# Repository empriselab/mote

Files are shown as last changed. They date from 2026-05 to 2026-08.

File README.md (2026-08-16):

# Mote





The low cost, high reliability mobile robot for hands-on robotics education.

[](mote/mote-book/src/assets/glam.webp)

## Motivation

Robotics is more fun with real hardware.

["Low cost"](https://www.robotshop.com/products/clearpath-robotics-turtlebot-4-mobile-robot) robots are prohibitively expensive for aspiring engineers.
We believe robotics should be affordable, enjoyable, and obtainable. So we made Mote.

## History

Mote is the spiritual successor of [the Little Red Rover project](https://github.com/little-red-rover).

For the past two years, Little Red Rover has been used to teach the Foundations of Robotics course at Cornell University.
Mote is the product of the many lessons learned during that effort.

## Contributing

Want to patch a bug, add a feature, or otherwise improve Mote?
Checkout [the contribution guide](https://empriselab.github.io/mote/advanced/contributing/contributing.html).

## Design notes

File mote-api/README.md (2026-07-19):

# mote-api

sans-io message and wire-protocol definitions for the Mote firmware <--> host driver link. 
`no_std` + `alloc`.

## Usage

```rust
use mote_api::{HostLink, MoteLink};
use mote_api::messages::host_to_mote;

let mut host_side = MoteLink::new();
let mut mote_side = HostLink::new();

host_side.send(host_to_mote::Message::Ping).unwrap();
while let Some(packet) = host_side.poll_transmit() {
    mote_side.handle_receive(&packet);
}
assert_eq!(mote_side.poll_receive().unwrap(), Some(host_to_mote::Message::Ping));
```

See [docs.rs/mote-api](https://docs.rs/mote-api) for the full API.

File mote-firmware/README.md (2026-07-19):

# mote-firmware

Embassy firmware for the RP2534 that runs mote.

## Build and Deploy

Requirements:
* [cargo](https://rustup.rs) (rust package manager)
* [go-task](https://taskfile.dev/installation/) (task runner)
* [probe-rs](https://probe.rs/docs/getting-started/installation/) (flasher / debugger)

From this folder, run

```
task deploy
```

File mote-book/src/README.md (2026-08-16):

<pre style="text-align: center">
         ┓            ┏         
░░░░░▒▒▒▓┃ ┳┳┓┏┓┏┳┓┏┓ ┃▓▒▒▒░░░░░
░░░░░▒▒▒▓┃ ┃┃┃┃┃ ┃ ┣  ┃▓▒▒▒░░░░░
░░░░░▒▒▒▓┃ ┛ ┗┗┛ ┻ ┗┛ ┃▓▒▒▒░░░░░
         ┛            ┗         
</pre>

<p style="text-align: center"> The low-cost, high-reliablity mobile robot for hands-on robotics education. </p>

<br>
<br>

<div class="image-split">
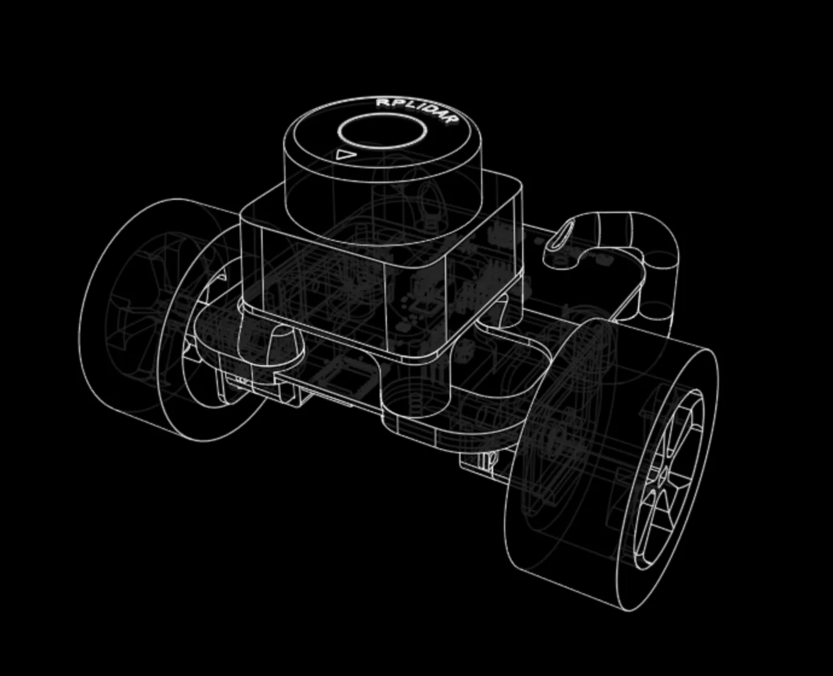
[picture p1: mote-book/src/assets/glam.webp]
    
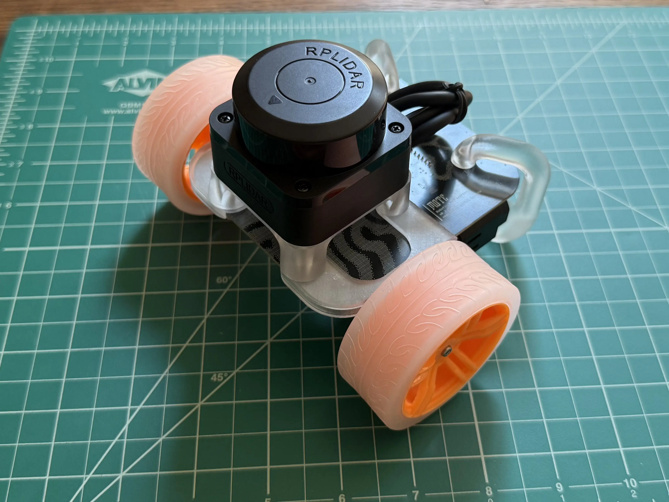
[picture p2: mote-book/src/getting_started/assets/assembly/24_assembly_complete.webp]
    
</div>

<div class="desktop-only">
    <iframe src="https://app.rerun.io/version/0.34.1/index.html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" width="100%" style="aspect-ratio: 1.5;"></iframe>
</div>

## Highlights

* LiDAR, IMU, and wheel position data streamed over WiFi
* Polished SDKs for ROS, ROS2, Python and Rust
* Wide cross-platform support
* Open source firmware, software, and hardware
* Only $100

## Getting Started

[Assemble your kit](./getting_started/kit-assembly.md) if you already have the parts, or checkout the [hardware sourcing guide](./hardware-sourcing/acquire.md) if you're starting from scratch.

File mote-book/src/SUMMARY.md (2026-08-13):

# Summary

[Home](README.md)

# Getting Started

- [Kit Assembly](./getting_started/kit-assembly.md)
- [Updating Firmware](./getting_started/updating.md)
- [Configuration](./getting_started/configuration.md)
- [Hello World](./getting_started/hello-world.md)

# Guides

- [Python]()
    - [Visualization]()
    - [Teleop]()

- [Rust]()
    - [Visualization]()
    - [Teleop]()

- [ROS Noetic (EOL)]()
    - [Visualization]()
    - [Teleop]()
    - [Navigation]()

- [ROS2]()
    - [Visualization]()
    - [Teleop]()
    - [Nav2]()

# Troubleshooting

- [Common Issues](./troubleshooting/common_issues.md)
- [Status LEDs](./troubleshooting/status_leds.md)

# Hardware Sourcing

- [Get Your Mote](./hardware-sourcing/acquire.md)
- [Bill of Materials]()
- [Ordering Circuit Boards]()
- [3D Printed Parts]()

# Advanced

- [Contributing](./advanced/contributing/contributing.md)
    - [Development Environment](./advanced/contributing/dev_env.md)
    - [Building, Testing, Running, and Releasing](./advanced/contributing/build_test_deploy.md)
    - [Hardware](./advanced/contributing/hardware.md)

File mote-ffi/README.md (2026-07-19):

# mote-ffi

FFI glue exposing [mote-api](../mote-api)'s message protocol to Python, WASM, and C++.

## Python: `mote_link`

The Python package. See [`mote_link/README.md`](mote_link/README.md) for
installation and usage.

```bash
task dev-setup   # builds the extension and regenerates types
task test        # cargo test + wasm-pack test + pytest
```

## C++

```bash
task build-cxx
```

Builds a static library (`target/release/libmote_ffi.a`) and cxx-generated headers
(`include/mote-ffi/src/mote_cxx.rs.h`, `include/rust/cxx.h`). `#include "mote-ffi/src/mote_cxx.rs.h"`
to get the `mote::MoteLink` class, `mote::SendResult`/`mote::ReceiveResult`, and
`mote::MoteLinkErrorCode`. #

# WASM / TypeScript

```bash
task build-wasm
```

Builds a `wasm-pack` package (`target/pkg-node`) exposing a `Link` class. See
`mote-configuration`'s `src/lib/link.ts` for an example consumer.

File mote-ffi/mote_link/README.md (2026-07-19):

# mote_link

Python client for talking to [Mote](https://empriselab.github.io/mote/) robots over the network.

`mote_link` handles discovery (via mDNS), connection, and message serialization / deserialization.

## Installation

```bash
pip install mote_link
```

Add the `demo` extra (`pip install mote_link[demo]`) to also install `rerun-sdk` and
`pyglet`, needed only by the bundled `rerun-demo` example.

## Example

```python
import asyncio

from mote_link import MoteClient, SetDriveBaseVelocity, DriveBaseState

async def main():
    async with MoteClient() as mote:
        # Opens an interactive prompt if the robot's IP or UID isn't known.
        await mote.connect()

        # Drive both wheels forward.
        await mote.send(SetDriveBaseVelocity(left_velocity_rad_per_s=1.0, right_velocity_rad_per_s=1.0))

        # Read messages from the robot.
        message = await mote.recv()
        if isinstance(message, DriveBaseState):
            print(f"left: {message.left}, right: {message.right}")

asyncio.run(main())
```

## Documentation

See the [Mote documentation](https://empriselab.github.io/mote/) for hardware setup, configuration,
and the full API reference.

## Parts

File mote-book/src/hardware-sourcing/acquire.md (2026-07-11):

# Get Your Mote

Mote uses a custom circuit board that must be manufactured and assembled at a factory.
While PCBA has become remarkably affordable in recent years, setup fees make the cost per unit high for small scale runs (1 - 10 units).

If you would like to order a small number of robots, please take a look on [the issue tracker](https://github.com/empriselab/mote/issues) and see if a group buy is being coordinated.
If you don't see a group buy posted, reach out to [a member of the Mote team](mailto:mmc323@cornell.edu) and we can help you start one.

If you would like to build many Motes you can start your own manufacturing run. Check out [Ordering Circuit Boards](./circuit-boards.md) for a step by step guide on the process.
It's much easier than it sounds.

All other (non-3D printed) parts are commercially available through standard channels. See the [Bill of Materials page](./bom.md) for details.

The rest of the robot is 3D printed. The [3D Printed Parts page](./printed.md) provides guidance for producing these parts.

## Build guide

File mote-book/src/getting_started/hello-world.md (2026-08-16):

# Hello World

In this example we'll use the mote-link Python library to control Mote and visualize telemetry data.

<div class="desktop-only">
    <iframe src="https://app.rerun.io/version/0.34.1/index.html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" width="100%" style="aspect-ratio: 1.5;"></iframe>

*Example data - Mote driving around my apartment*
</div>

<!-- <iframe src="https://app.rerun.io/version/0.34.1/index.html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" width="100%" style="aspect-ratio: 1.5;"></iframe> -->

## Setup

This example uses [uv](https://docs.astral.sh/uv/) to run a Python program. Install uv using the instructions in the [uv docs](https://docs.astral.sh/uv/getting-started/installation/).

Attach the battery to your Mote. Place your Mote on the ground with enough space for it to move around.

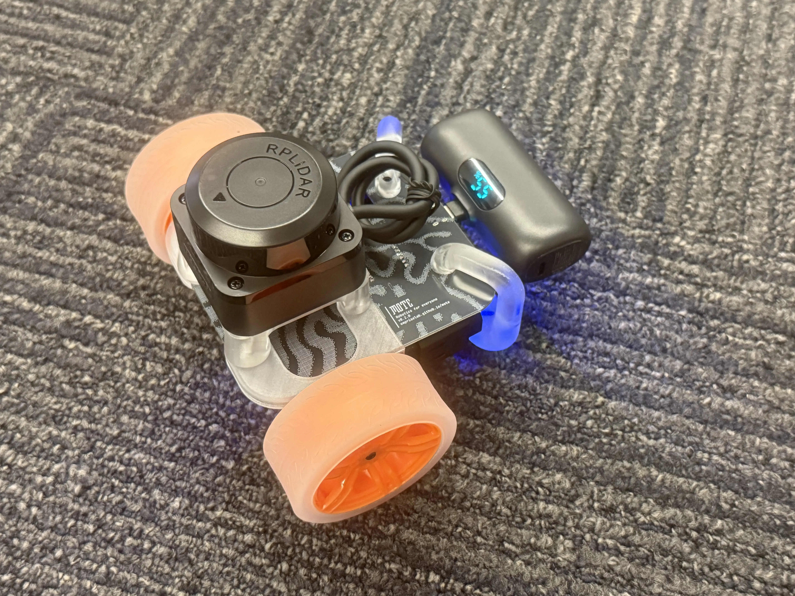
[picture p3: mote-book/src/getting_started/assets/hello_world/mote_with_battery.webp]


## Running the mote-link Demo

In the terminal of your choice, run the demo.

```bash
uvx --from 'mote-link[demo]' rerun-demo
```

Follow the instructions in your terminal to select and connect to your Mote. 

Once connected, your browser will open to a dashboard showing realtime LiDAR, wheel encoder, accelerometer, and gyroscope data.

Use the arrow keys to drive Mote around.

> [!TIP]
> If you know your robot's [name](./configuration.html#give-your-mote-a-name) or [ip address](./configuration.html#give-your-mote-a-name), you can skip waiting for autodiscovery by passing it in as an argument:
>
> `uvx --from 'mote-link[demo]' rerun-demo --ip 192.168.XX.XX` or 
> 
> `uvx --from 'mote-link[demo]' rerun-demo --name my-awesome-name`

## Next Steps

* [Python guide]() - learn how to write your own Python scripts for interfacing with Mote.
* [The Rust guide]() - like the Python guide, but using Rust 🦀.
* [The ROS 2 guide]() - learn how to use Mote with the Robot Operating System.

## Troubleshooting

### "Could not find Motes using autodiscovery"

Your network has mDNS disabled. This is common practice for public and corporate networks.
You can connect directly to your Mote via it's IP.

1. Connect the robot to your computer using a USB-C cable

2. Open [the Mote configuration page](../configuration).

3. Note the IP provided under "Identification".

4. Pass the IP into the demo command

```bash
uvx --from 'mote-link[demo]' rerun-demo --ip <IP from the configuration page>
```

Be aware that Mote's IP may change between sessions. If that happens, check the [configuration page](../configuration) for the new IP.

### My Mote drives backwards

[Check your motor cable connections](./kit-assembly.html#cables). Are the left and right motor connections swapped?

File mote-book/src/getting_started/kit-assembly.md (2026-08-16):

# Kit Assembly

In this tutorial you will assemble your Mote. It should take around 15 minutes.

## Gather Parts

First, check that you have the required parts.
Missing something? Check out [the sourcing guide](../hardware-sourcing/acquire.md).

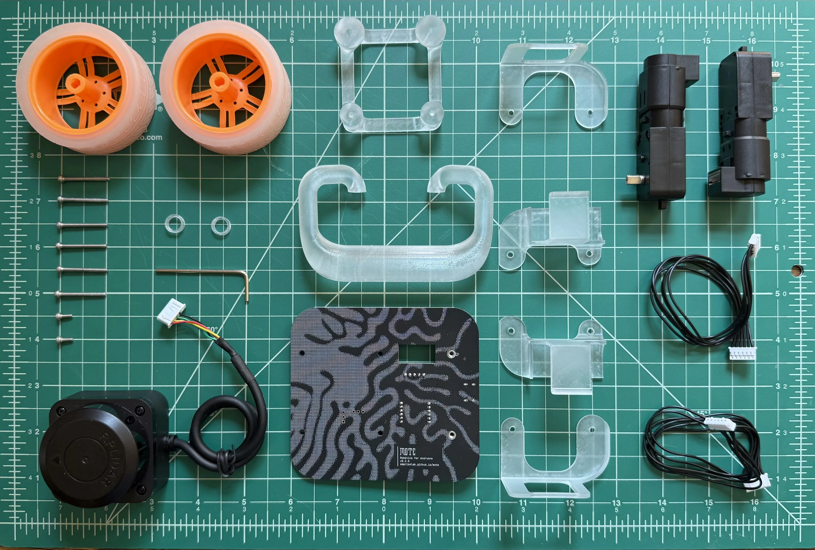
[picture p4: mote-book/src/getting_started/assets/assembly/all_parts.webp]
Required parts


| Item | Quantity | Picture | 
|---|---|---|
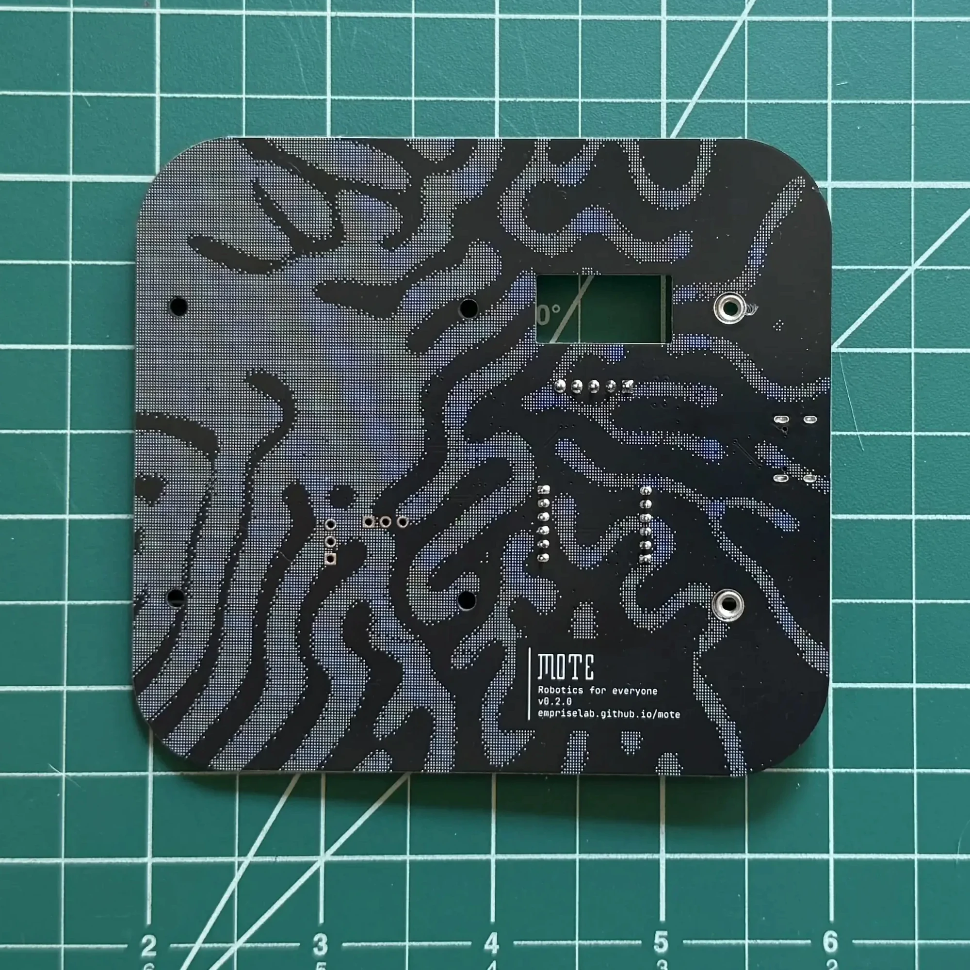
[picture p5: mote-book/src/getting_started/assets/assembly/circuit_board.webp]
| Circuit Board | 1 |  |
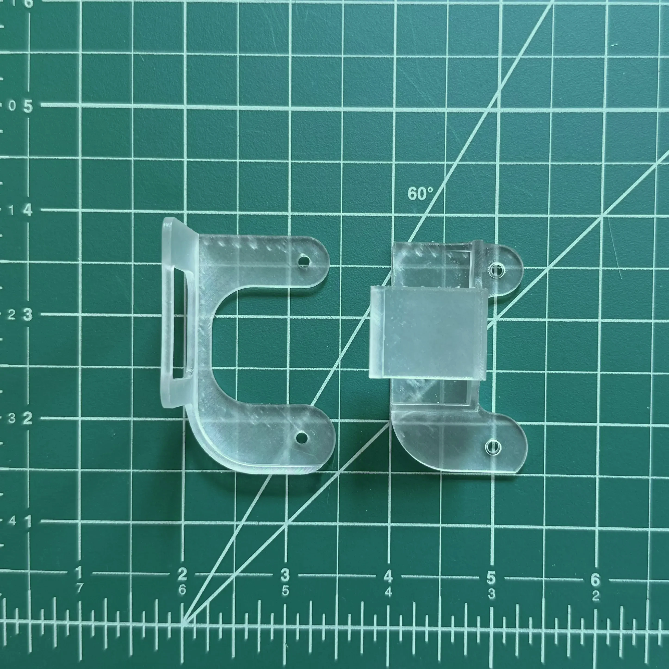
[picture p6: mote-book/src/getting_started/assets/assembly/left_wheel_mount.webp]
| Left Motor Mount | 1 |  |
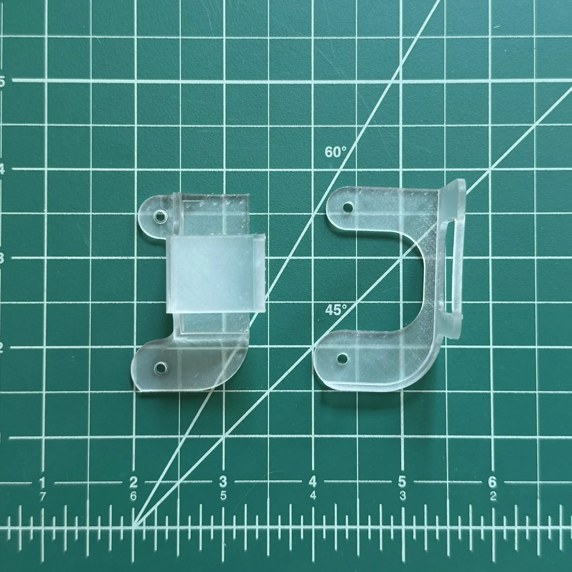
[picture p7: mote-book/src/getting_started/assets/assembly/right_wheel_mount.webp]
| Right Motor Mount | 1 |  |
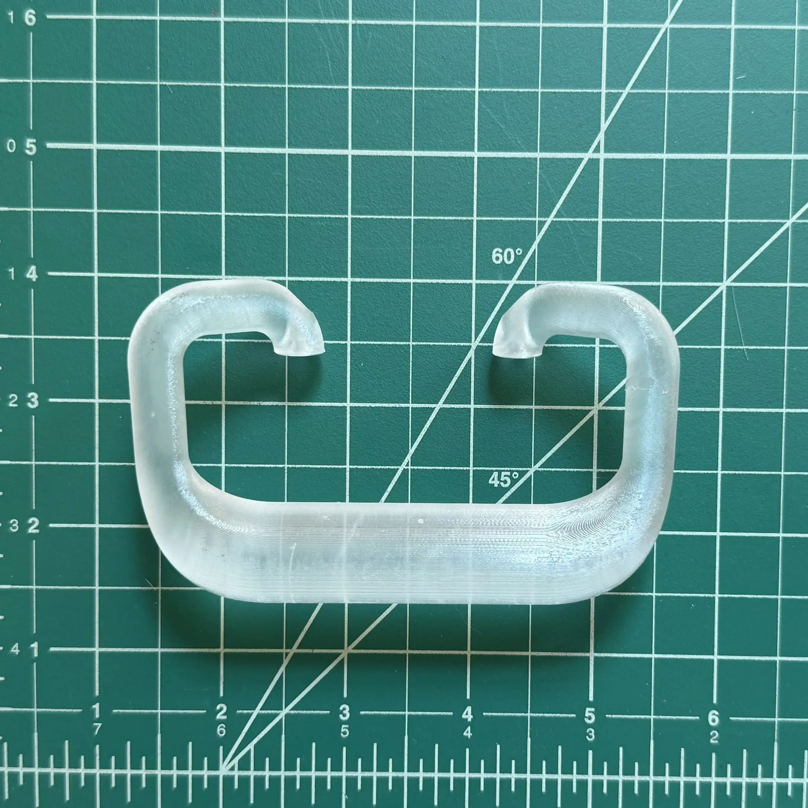
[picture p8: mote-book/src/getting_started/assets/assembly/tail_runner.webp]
| Tail Runner | 1 |  |
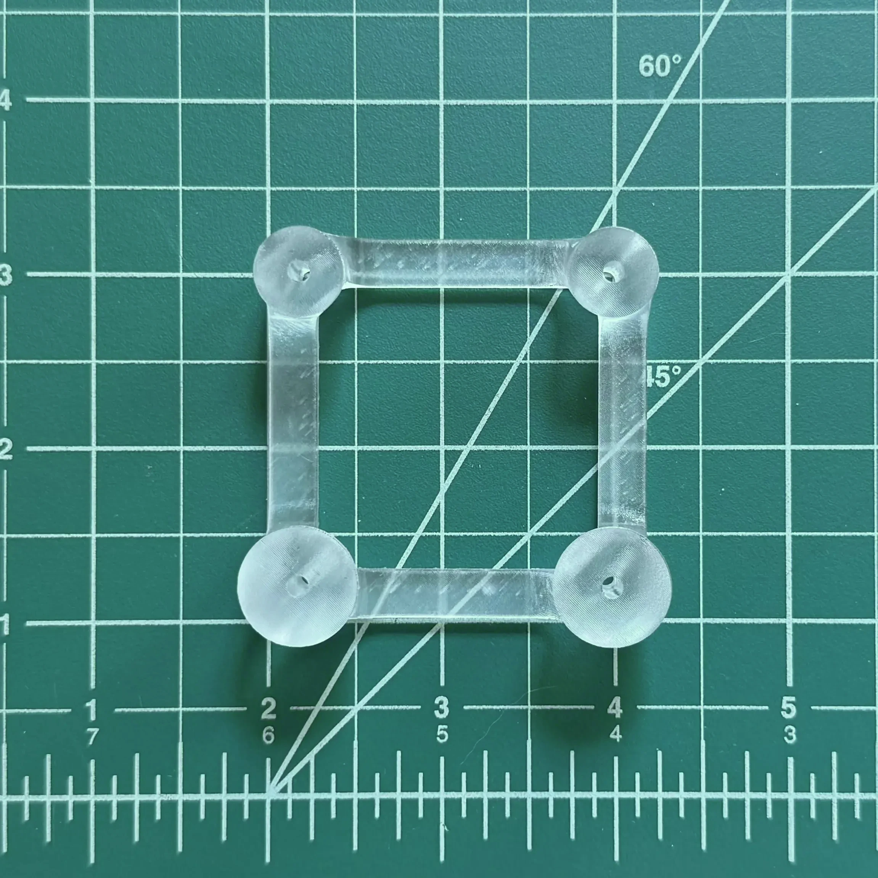
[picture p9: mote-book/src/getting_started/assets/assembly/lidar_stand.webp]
| LiDAR Mount | 1 |  |
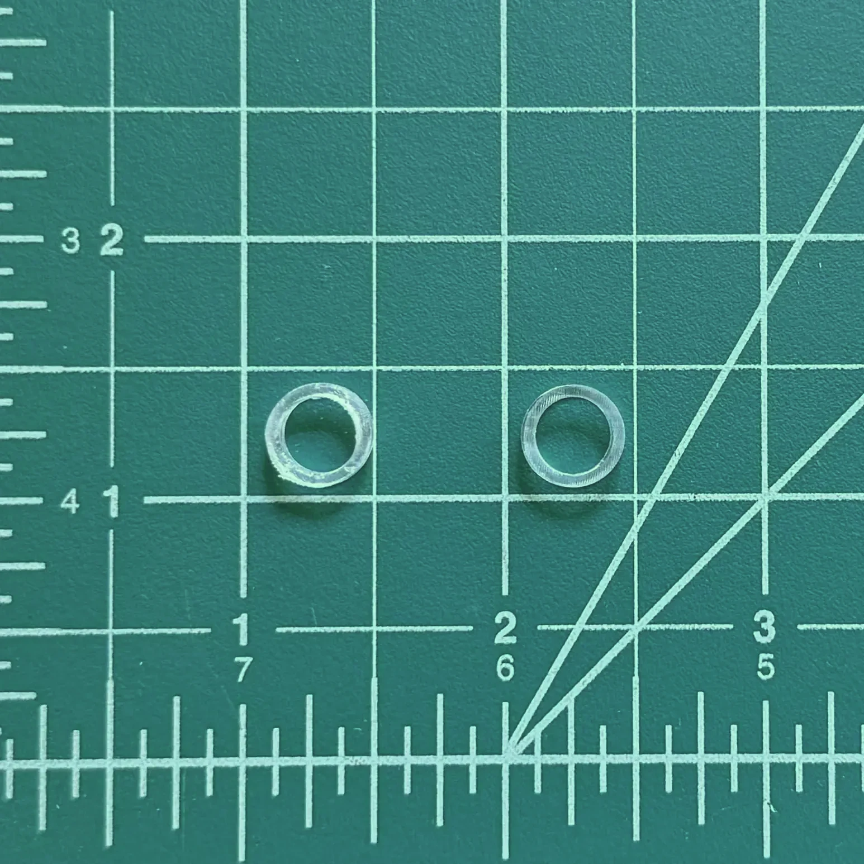
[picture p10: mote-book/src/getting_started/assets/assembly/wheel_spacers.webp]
| Wheel Spacers | 2 |  |
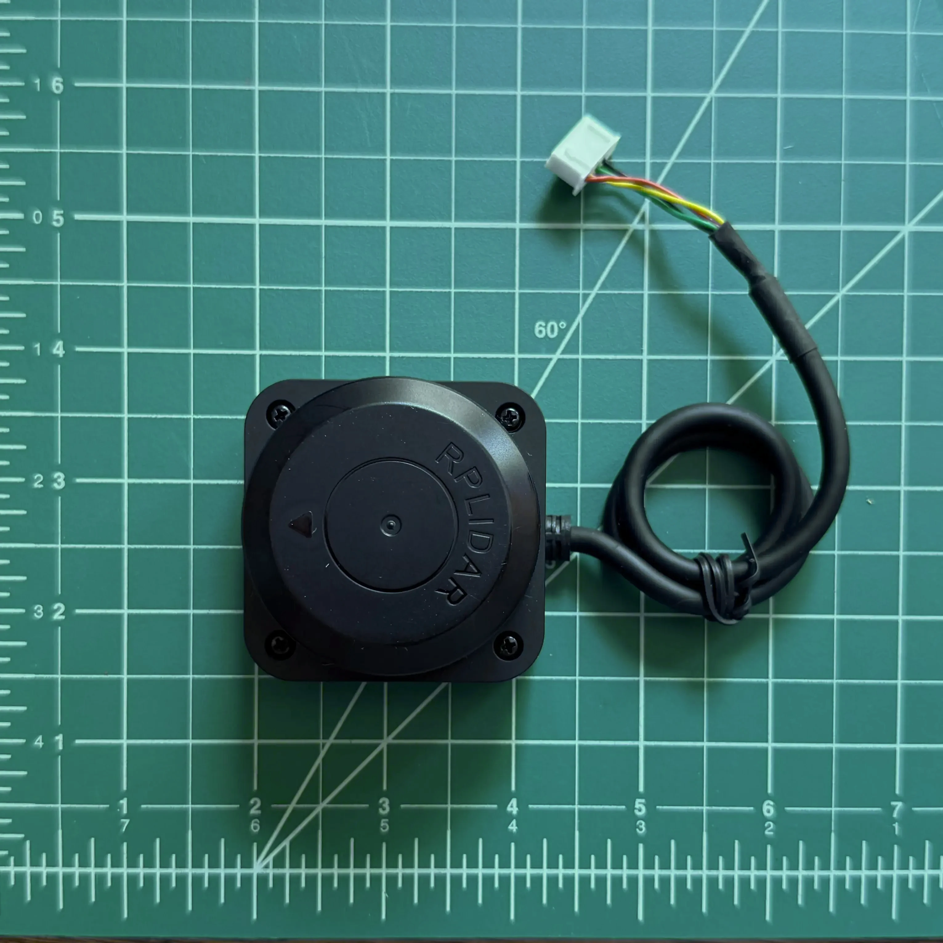
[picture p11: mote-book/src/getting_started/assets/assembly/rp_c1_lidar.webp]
| LiDAR | 1 |  |
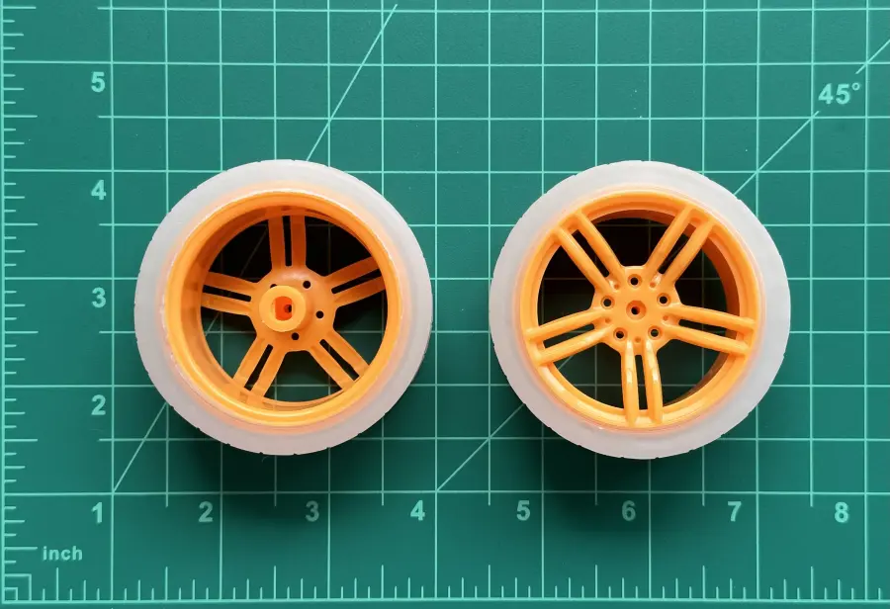
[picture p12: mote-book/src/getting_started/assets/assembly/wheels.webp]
| Orange Wheel | 2 |  |
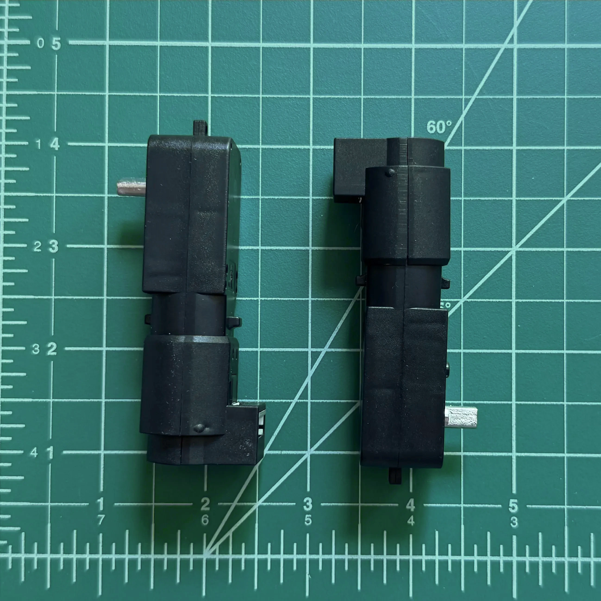
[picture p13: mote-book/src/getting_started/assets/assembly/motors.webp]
| Motor with Encoder | 2 |  |
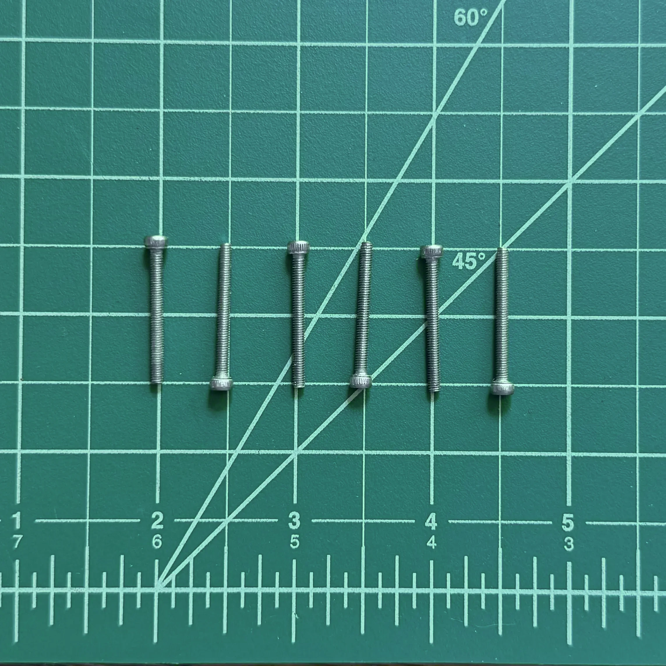
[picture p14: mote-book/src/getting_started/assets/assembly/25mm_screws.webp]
| 25mm M2.5 Hex Head Machine Screws | 6 |  |
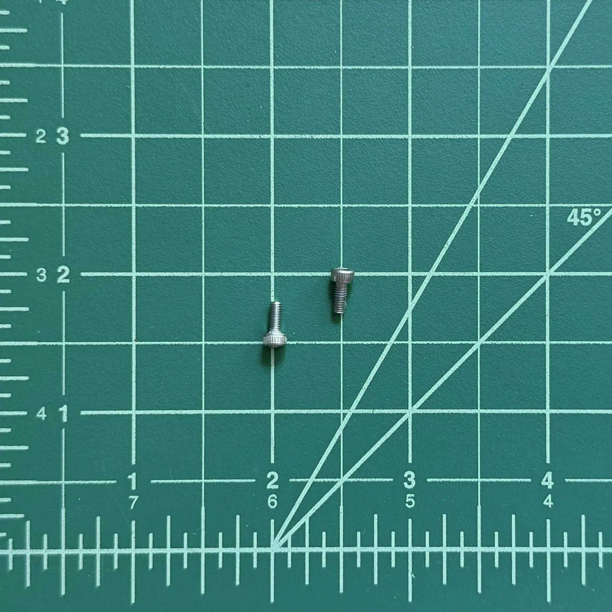
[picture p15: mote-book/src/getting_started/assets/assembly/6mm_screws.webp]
| 6mm M2.5 Hex Head Machine Screws | 2 |  |
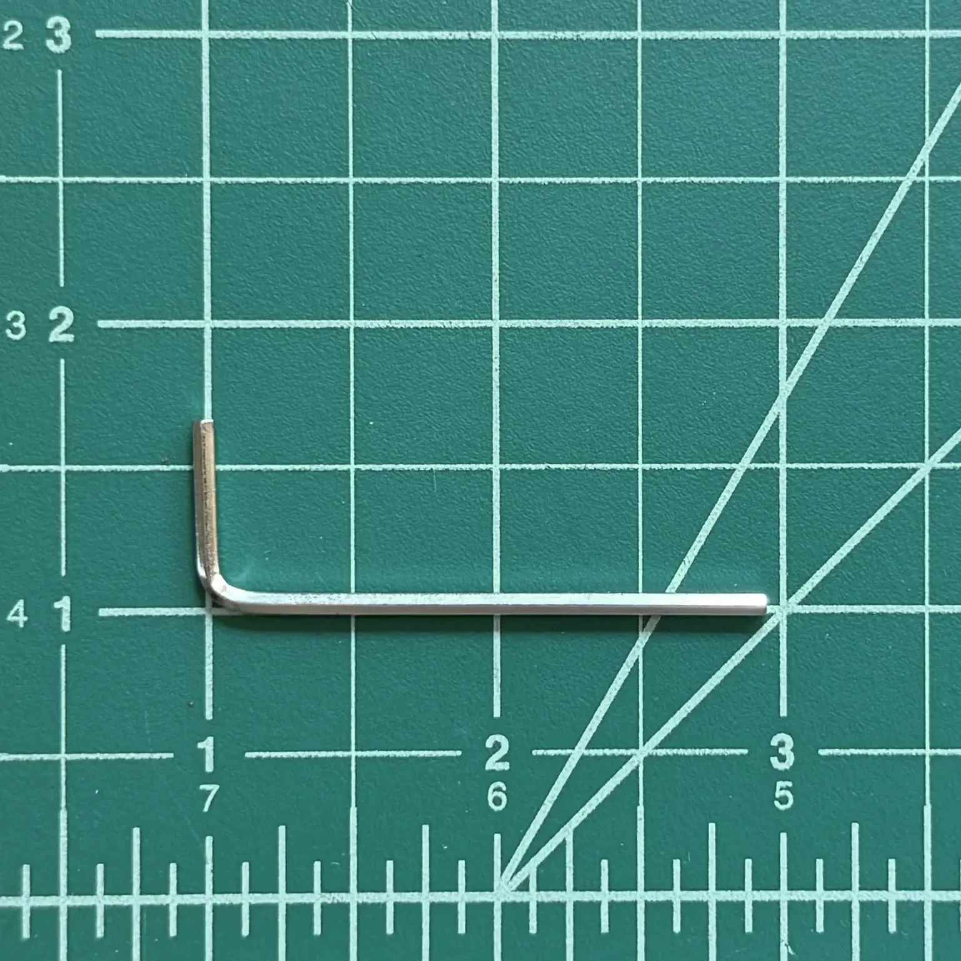
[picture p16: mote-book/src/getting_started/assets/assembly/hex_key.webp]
| 2mm Hex Key | 1 |  |
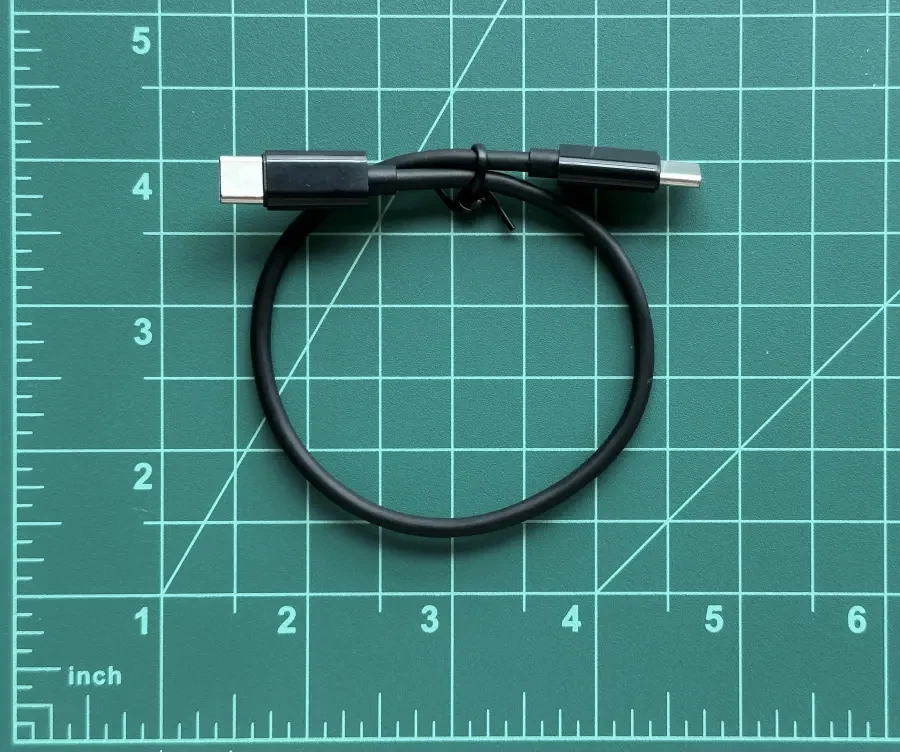
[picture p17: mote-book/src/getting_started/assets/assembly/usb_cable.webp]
| USB-C to C Cable | 1 |  |
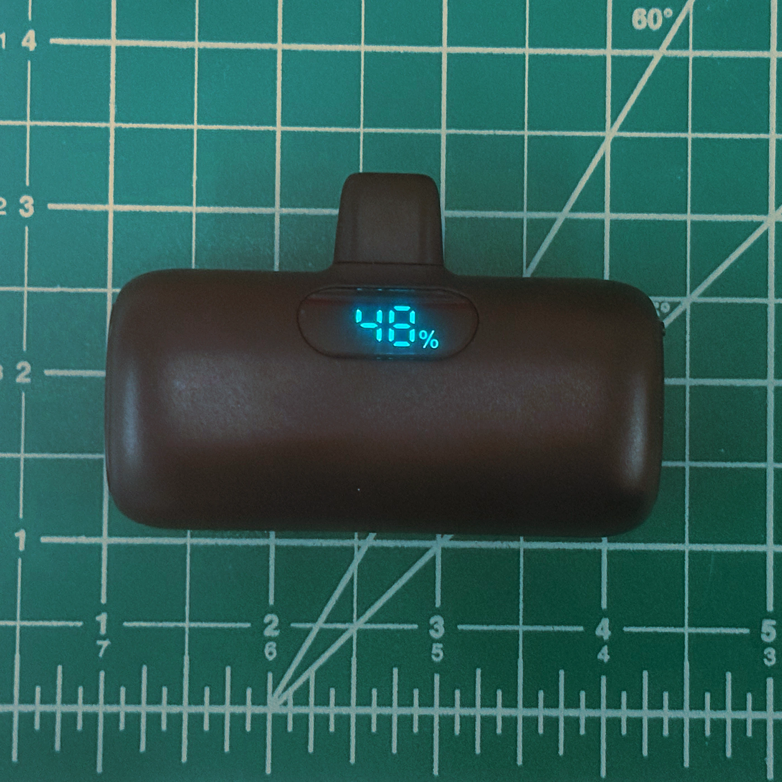
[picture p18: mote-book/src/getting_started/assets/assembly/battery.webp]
| 5000 mAh USB Portable Battery  | 1 |  |

## Motor Subassembly

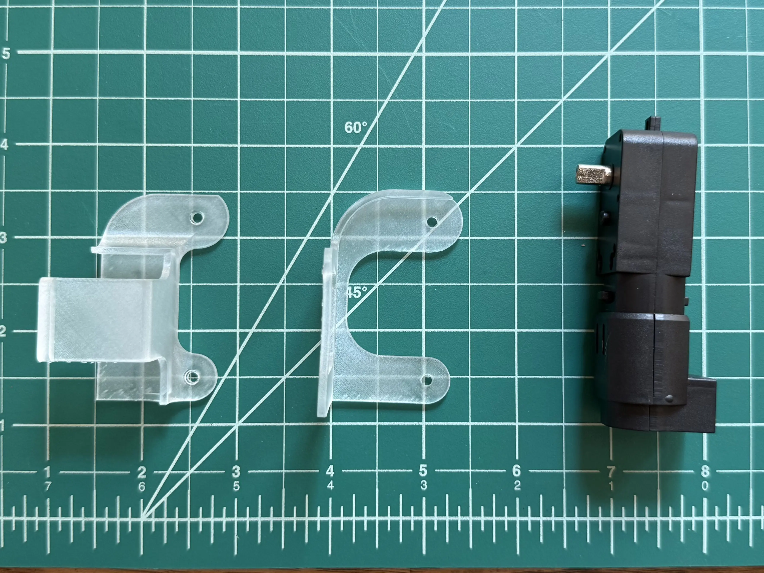
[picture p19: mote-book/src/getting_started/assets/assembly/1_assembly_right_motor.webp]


Place the motor into the bottom half of the motor mount. 
Ensure that the motor is seated in the pocket of the mount.

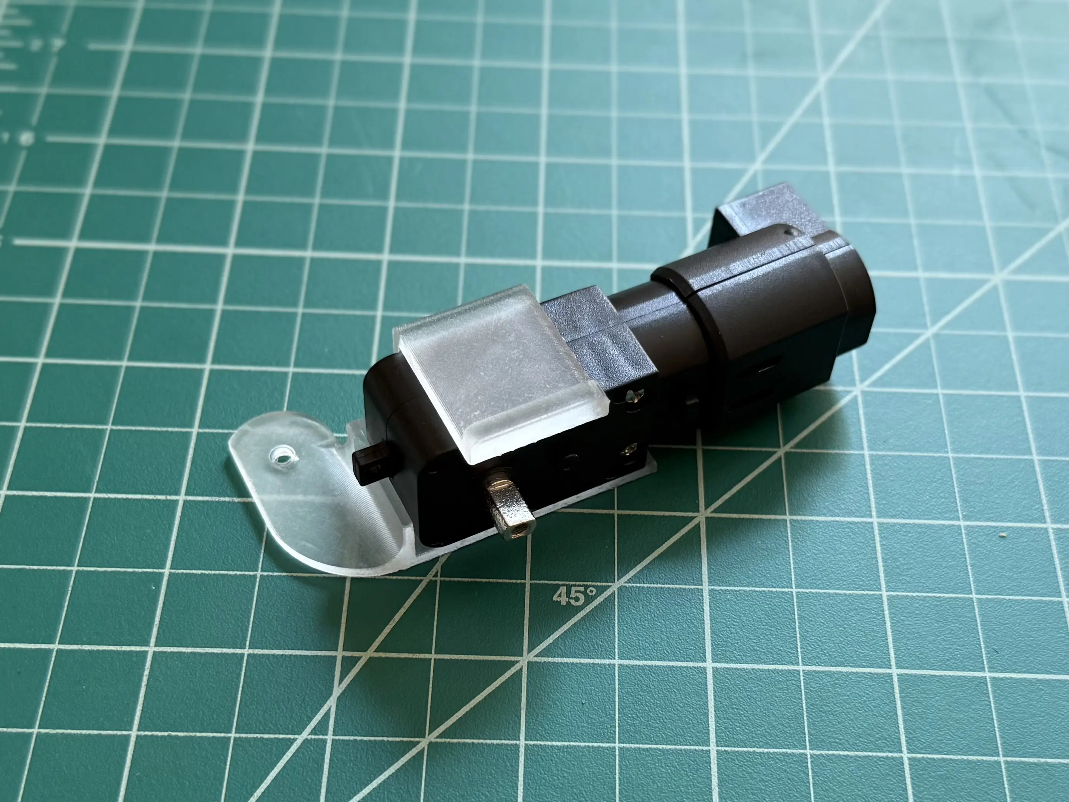
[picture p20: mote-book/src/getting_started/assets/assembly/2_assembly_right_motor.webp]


Connect the top side of the motor mount to the bottom side, securing the motor.

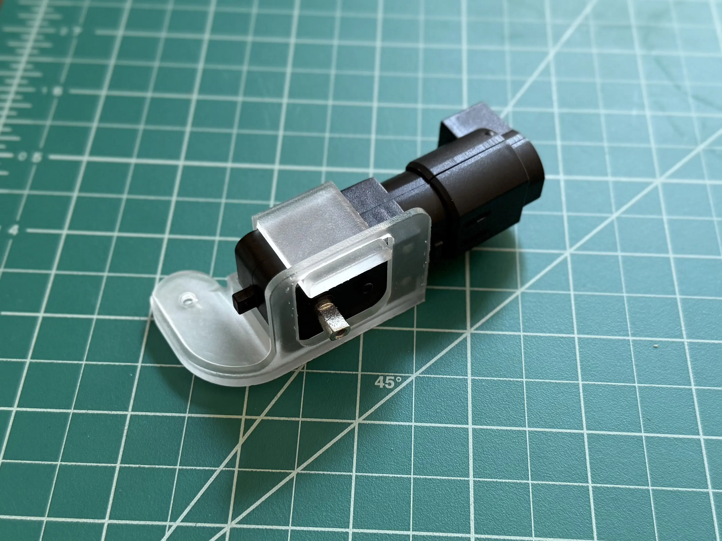
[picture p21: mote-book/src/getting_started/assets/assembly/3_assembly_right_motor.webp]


Repeat for the left side motor mount. 

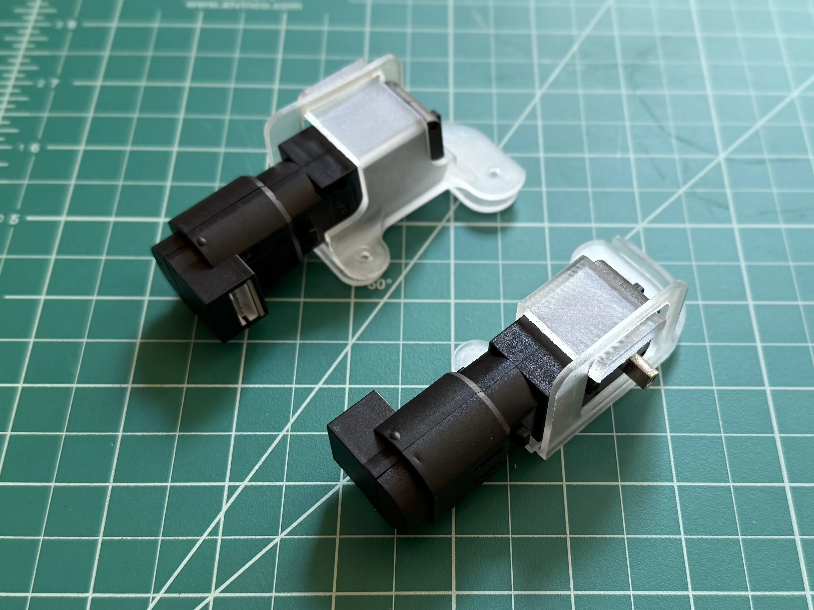
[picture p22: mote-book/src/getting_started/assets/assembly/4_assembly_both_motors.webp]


## Body Assembly

Slide the circuit board between the two halves of the motor mounts, aligning the holes in the mounts with those in the circuit board.

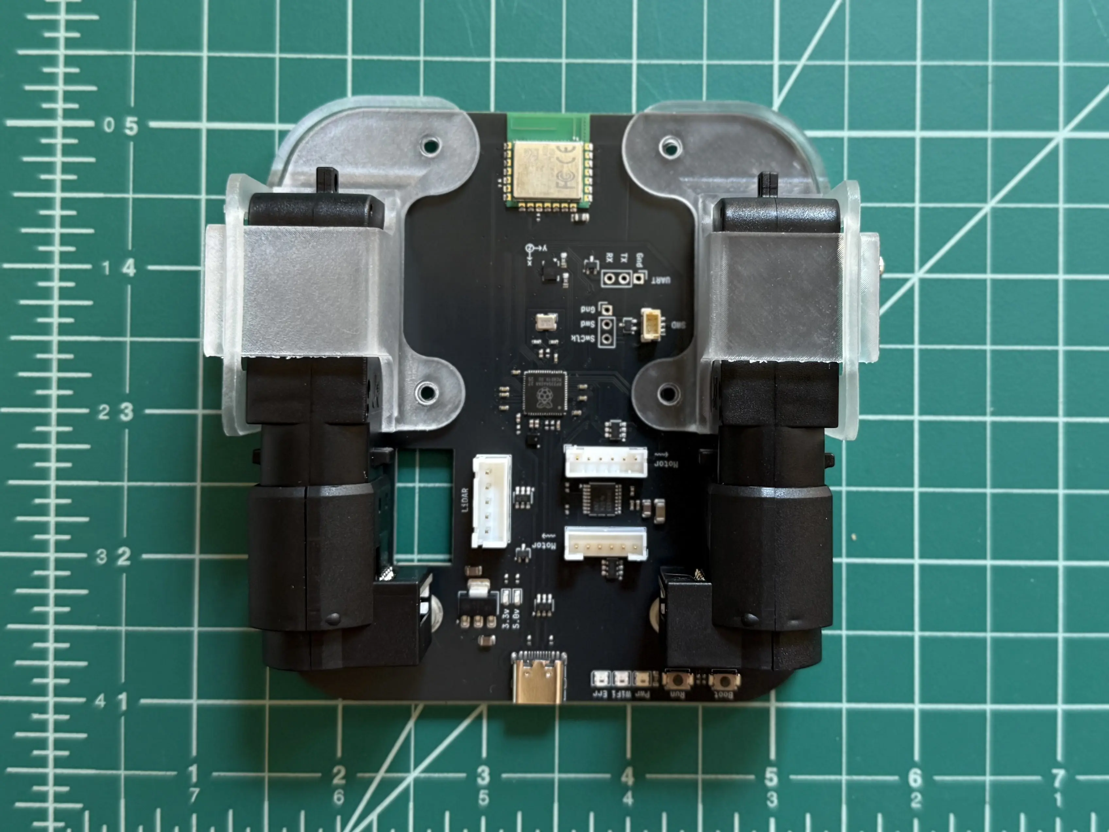
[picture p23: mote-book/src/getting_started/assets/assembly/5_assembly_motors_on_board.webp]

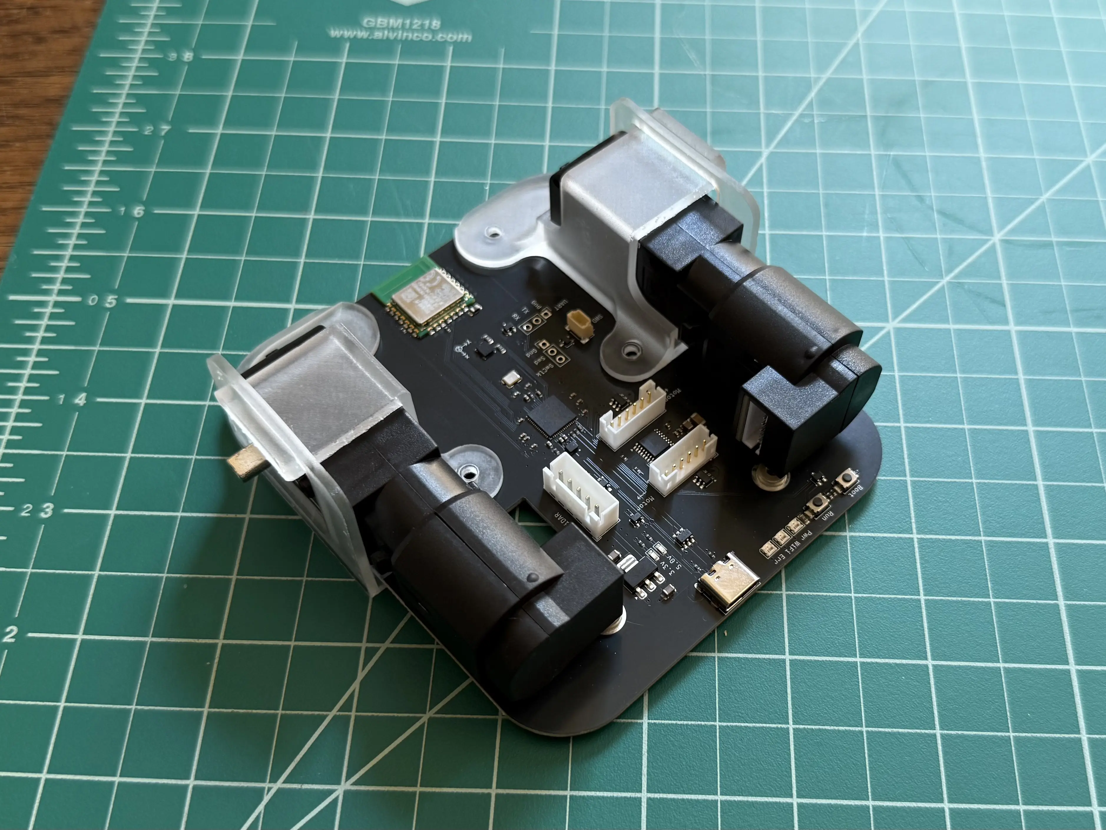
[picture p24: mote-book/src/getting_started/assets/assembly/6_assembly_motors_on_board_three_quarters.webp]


Insert the 25mm screws through the holes in the motor mounts and circuit board.

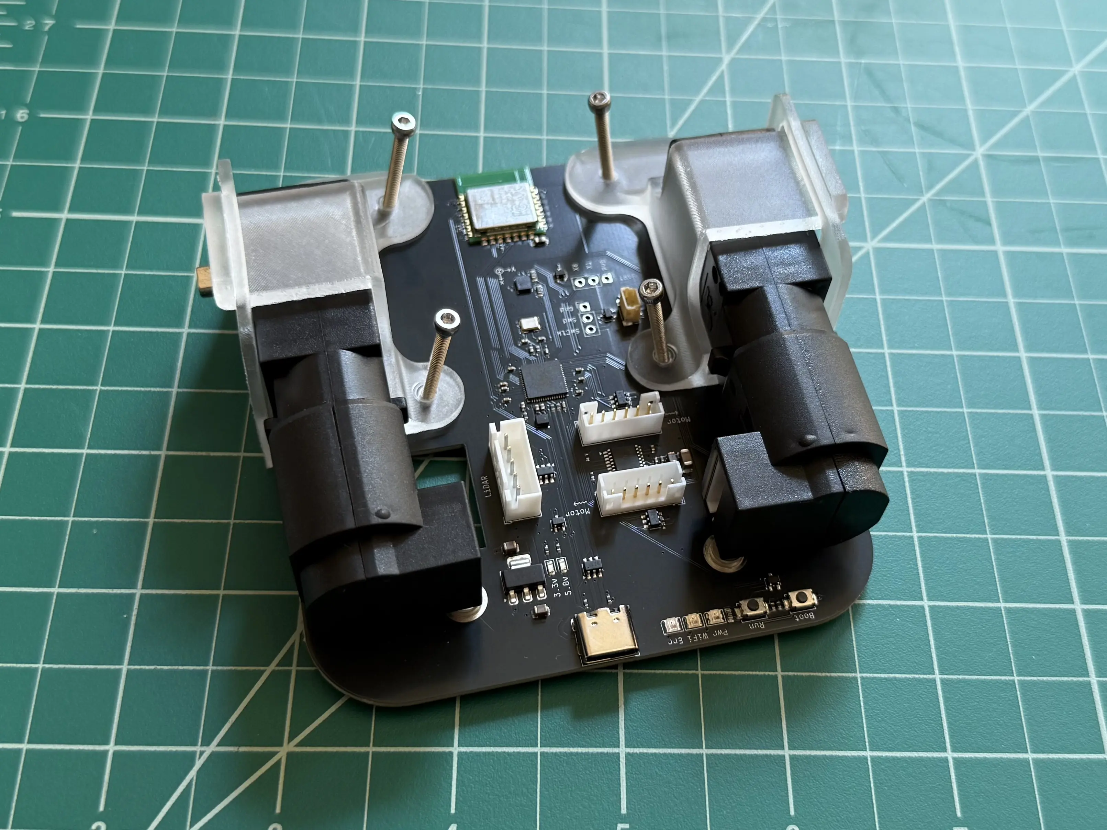
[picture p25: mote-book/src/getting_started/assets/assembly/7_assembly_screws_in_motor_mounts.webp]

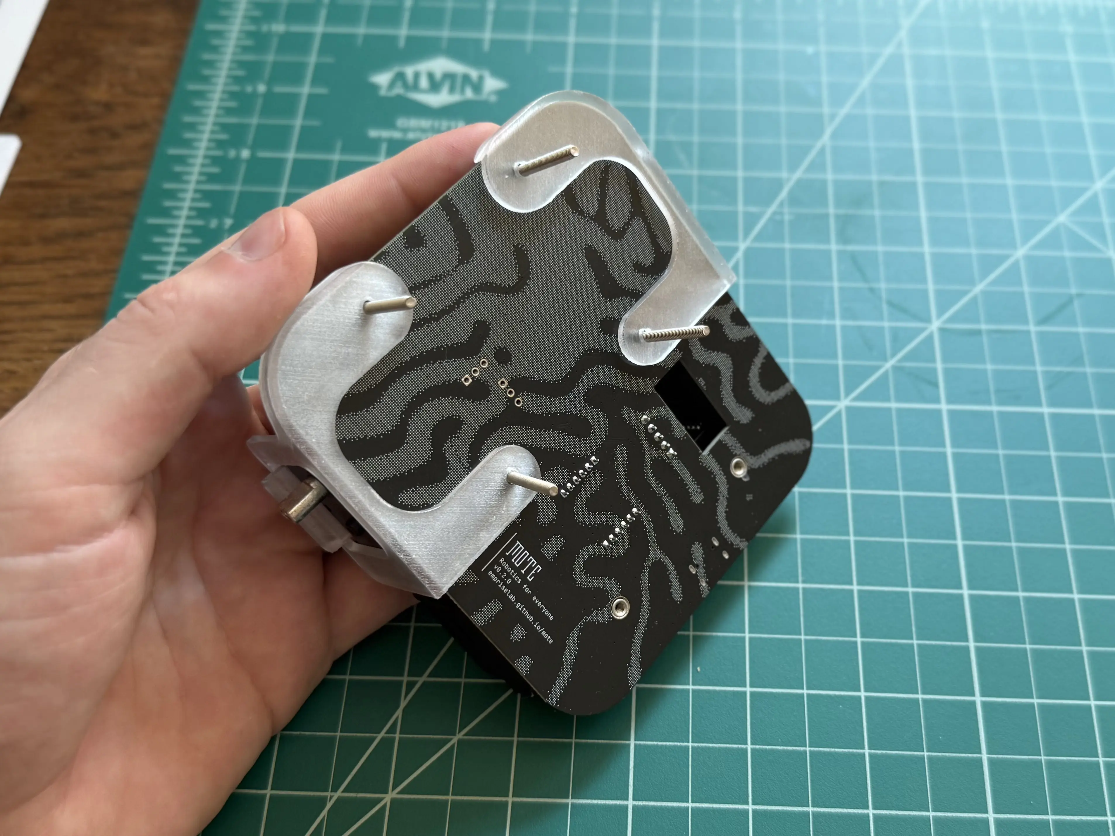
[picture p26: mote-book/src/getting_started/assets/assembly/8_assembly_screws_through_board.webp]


Place the LiDAR stand onto the 25mm screws. 

> [!TIP]
> The legs of the LiDAR stand are not all the same size. Match the radius of the legs with the radius of the motor mounts the legs are placed on.

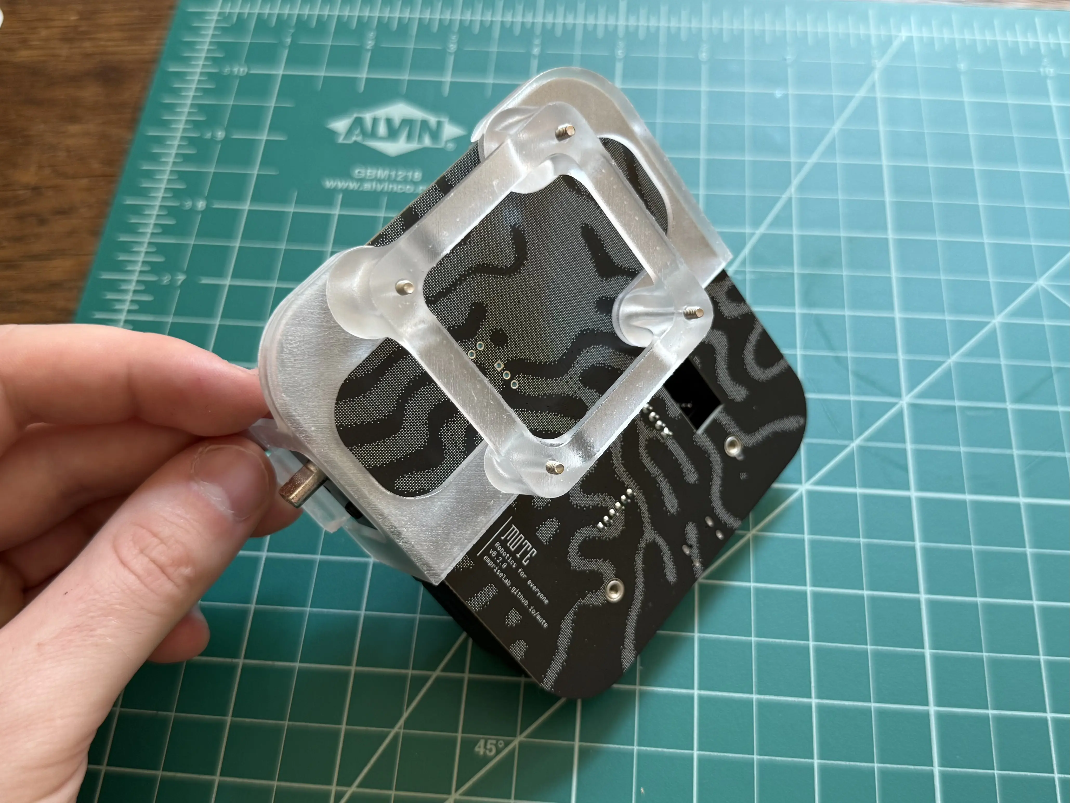
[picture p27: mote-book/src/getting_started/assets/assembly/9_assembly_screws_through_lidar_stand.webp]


Place the LiDAR on top of the LiDAR stand, then thread the 25mm screws into the LiDAR's base.

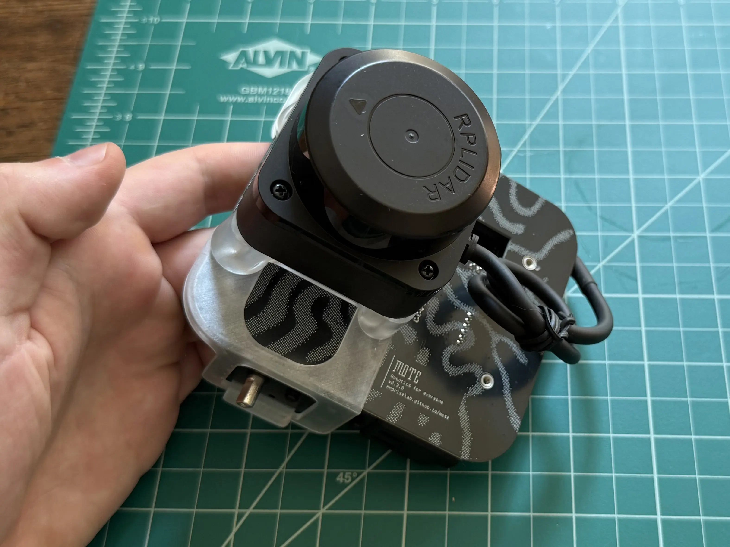
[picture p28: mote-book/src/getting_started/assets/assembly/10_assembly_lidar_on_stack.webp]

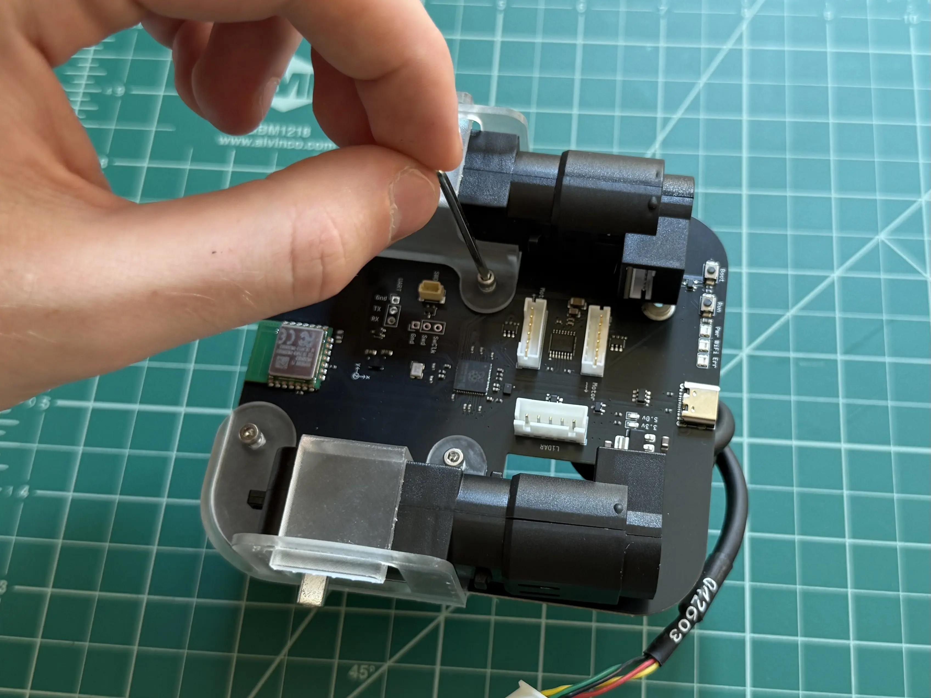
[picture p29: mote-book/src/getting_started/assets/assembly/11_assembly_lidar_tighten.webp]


## Cables

Connect both motors to the circuit board.

> [!IMPORTANT]
> It matters which motor is connected to which socket.
> Look for the "Motor" arrows on the silkscreen.
> The arrow points to the motor that should be connected to the respective socket.
>
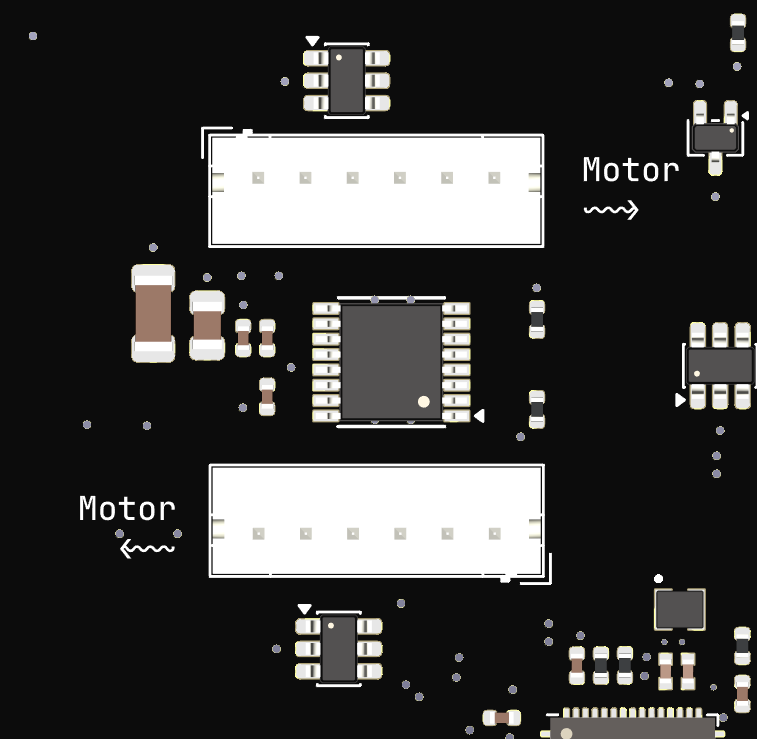
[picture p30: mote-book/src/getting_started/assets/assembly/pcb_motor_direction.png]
> 

<!-- ![](./assets/assembly/12_assembly_left_motor_cable.webp) -->
<!-- ![](./assets/assembly/13_assembly_left_motor_cable.webp) -->
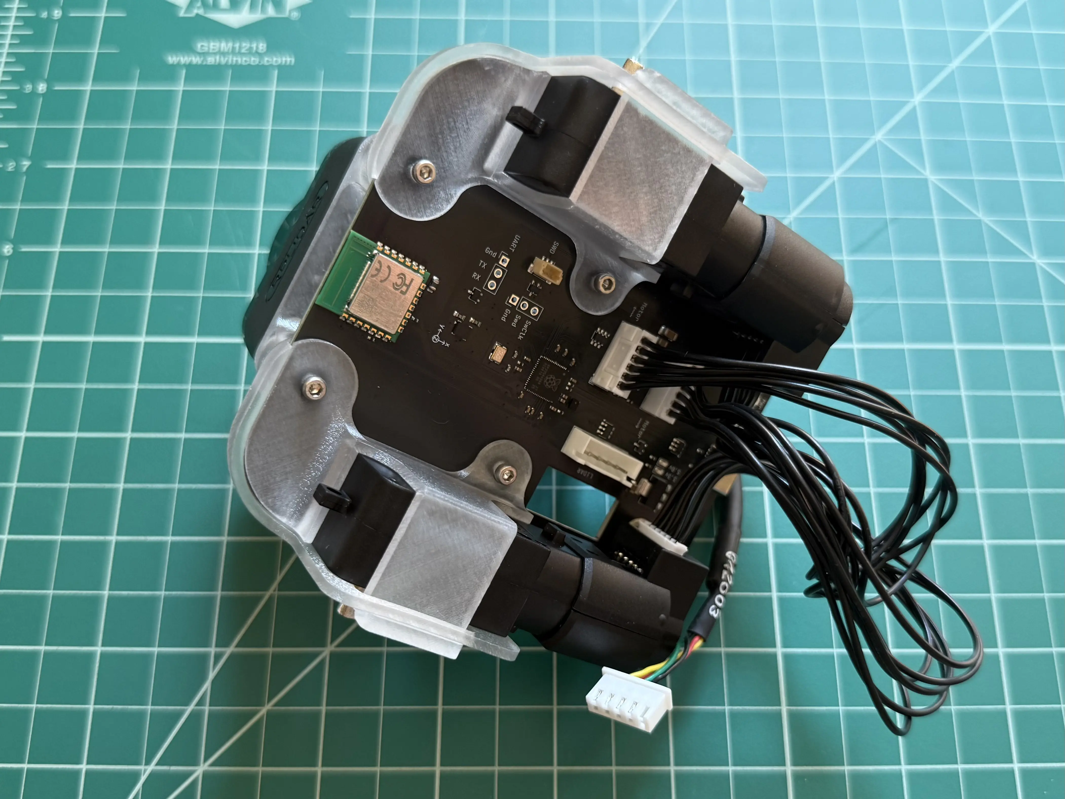
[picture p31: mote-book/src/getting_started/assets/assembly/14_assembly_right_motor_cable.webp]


Route the LiDAR's cable through the hole in the circuit board.

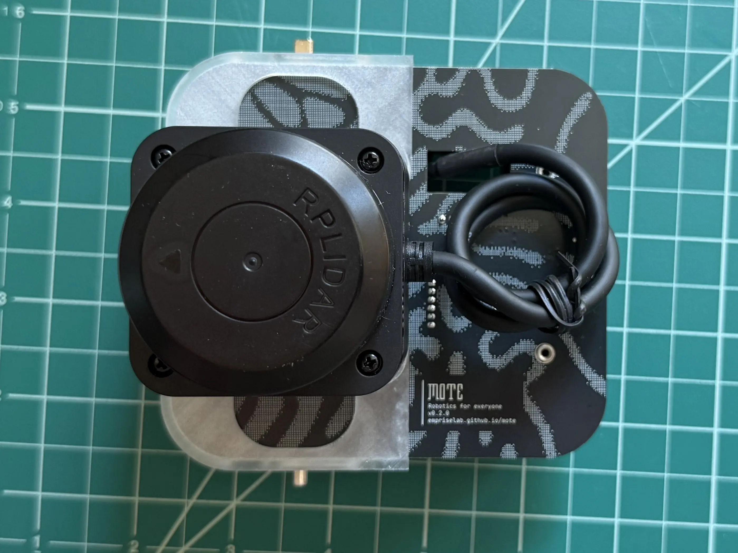
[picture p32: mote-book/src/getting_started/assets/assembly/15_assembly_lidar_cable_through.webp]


Connect the LiDAR's cable to the connector on the bottom of the circuit board labeled "LiDAR".

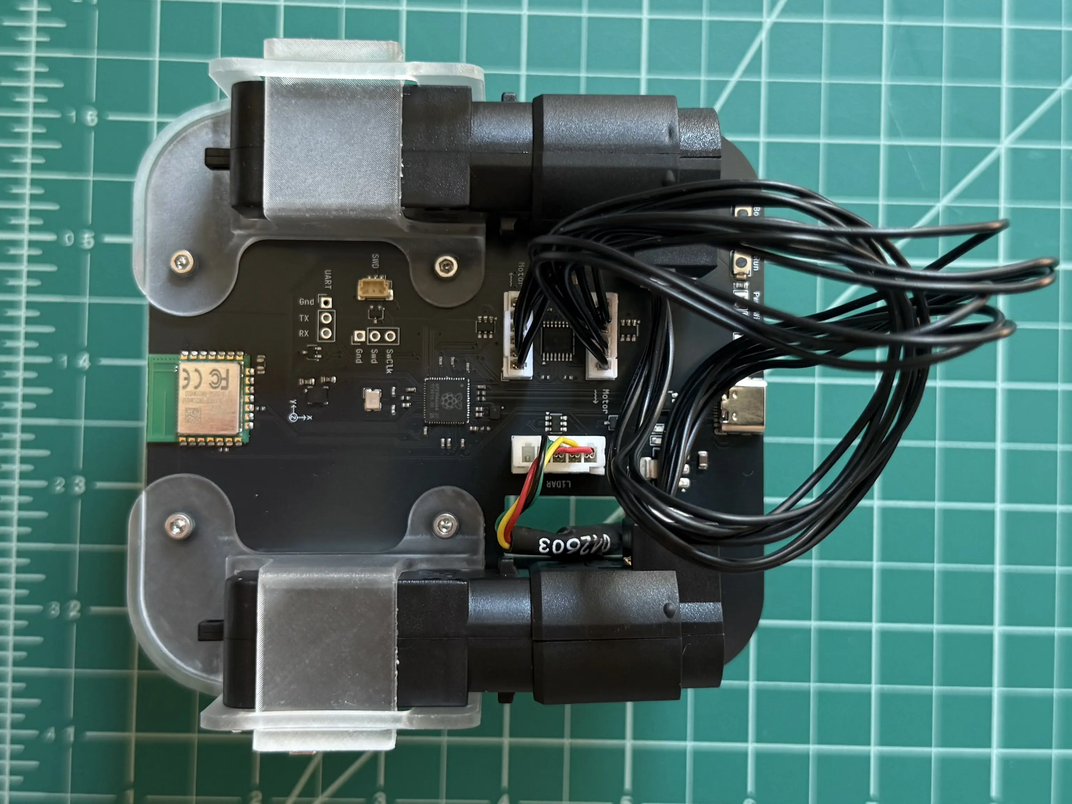
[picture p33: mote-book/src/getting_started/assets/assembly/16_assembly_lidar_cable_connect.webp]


Restrain the motor cables using a cable tie. Trim the cable tie to prevent dragging.

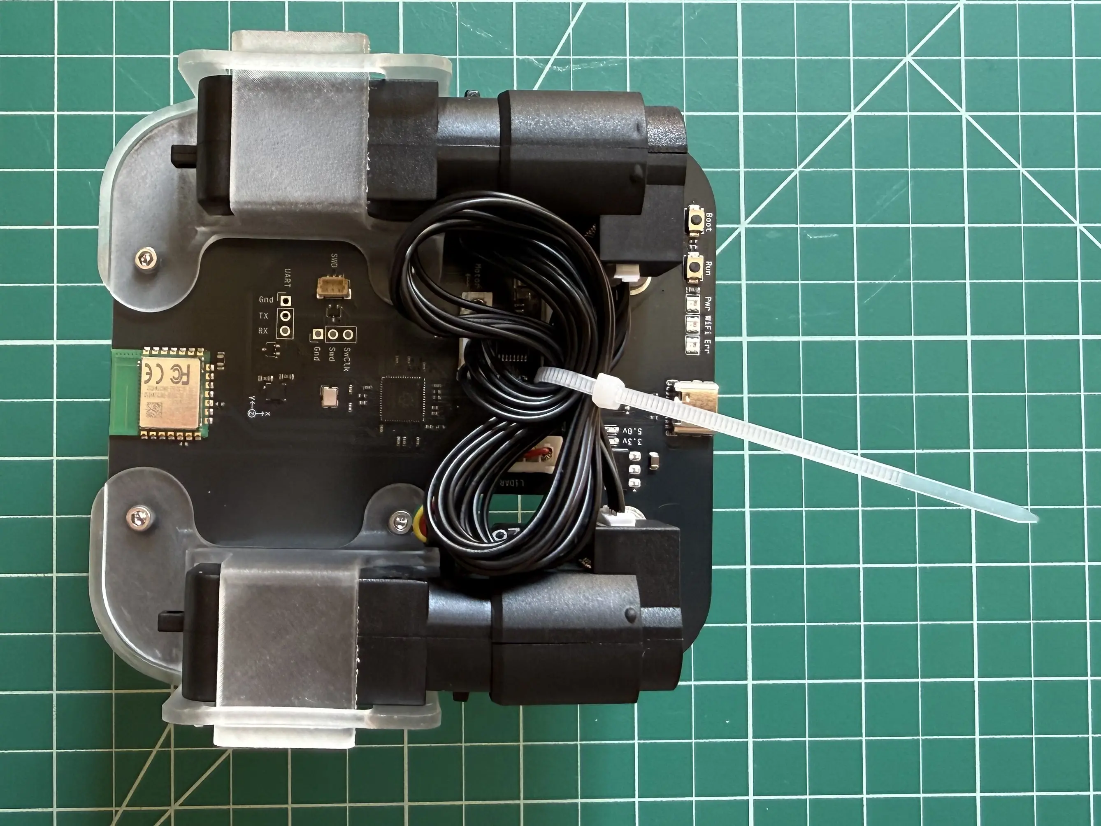
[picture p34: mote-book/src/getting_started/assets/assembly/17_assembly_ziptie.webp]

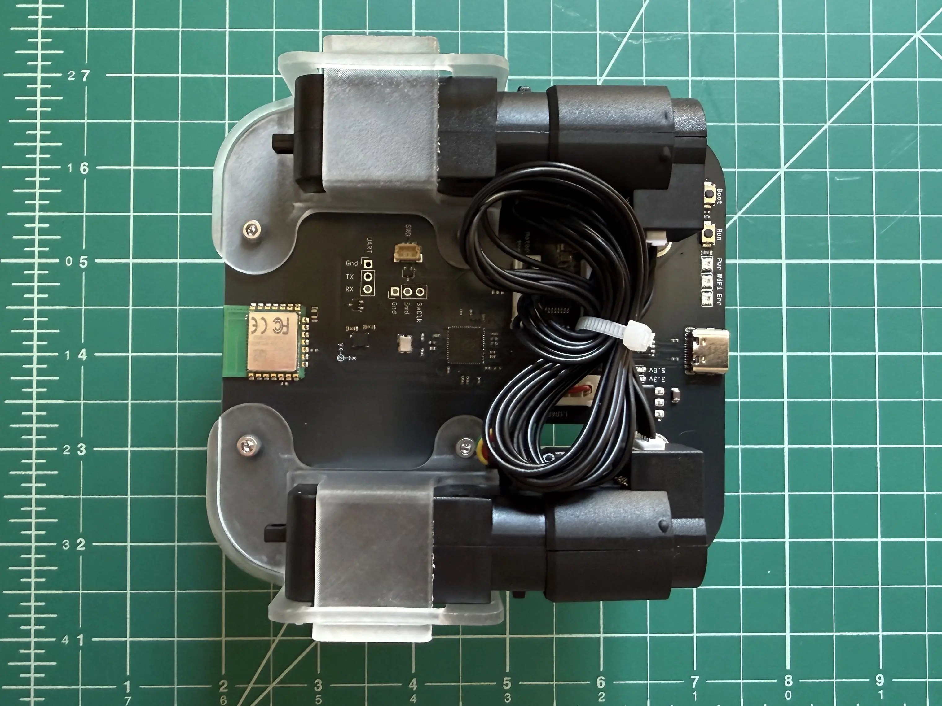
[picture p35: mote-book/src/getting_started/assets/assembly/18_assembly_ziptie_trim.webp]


## Wheels

Add a wheel spacer to the left motor.

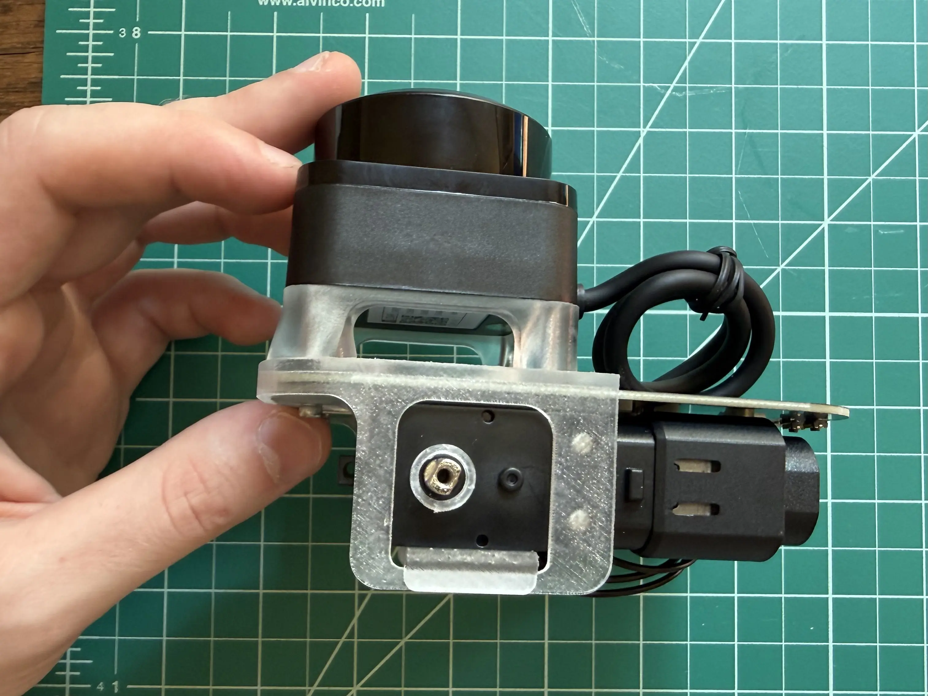
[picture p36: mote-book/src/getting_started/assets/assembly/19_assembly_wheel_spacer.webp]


Push the wheel onto the motor shaft.

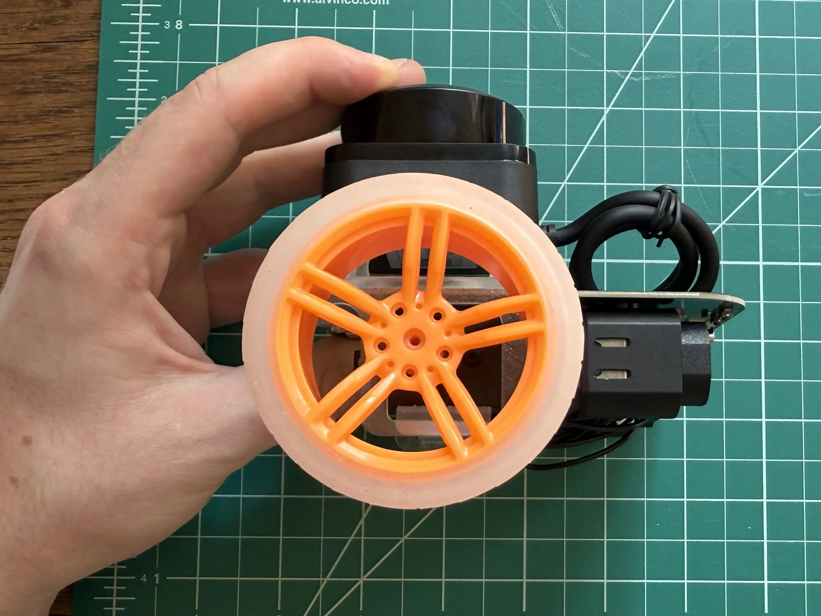
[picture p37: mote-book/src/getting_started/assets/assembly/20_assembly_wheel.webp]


Secure the wheel with a 25mm screw.

> [!TIP]
> The M2.5 screw must be threaded into the hole on the wheel. You may need to apply some pressure to get the thread started.

<div class="image-split">
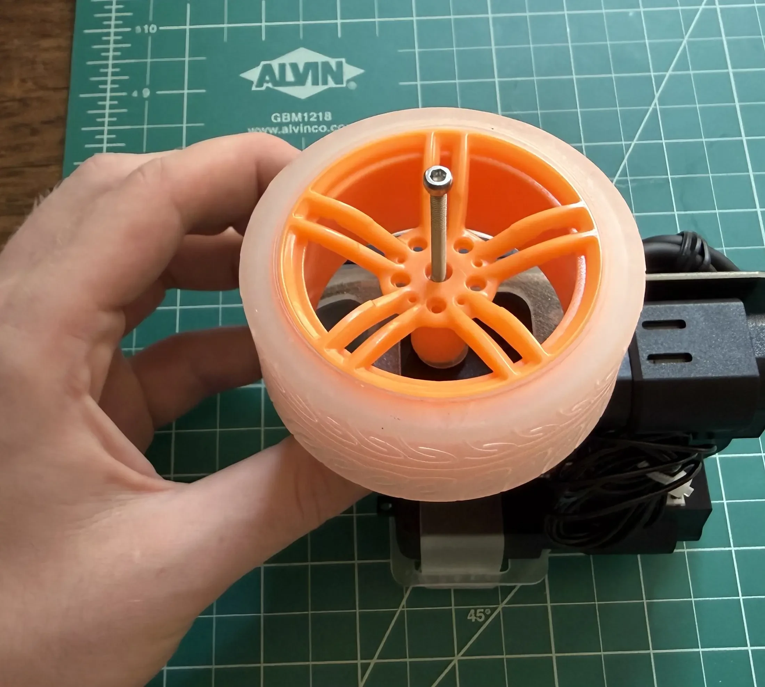
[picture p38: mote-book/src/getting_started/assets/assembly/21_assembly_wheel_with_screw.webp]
     
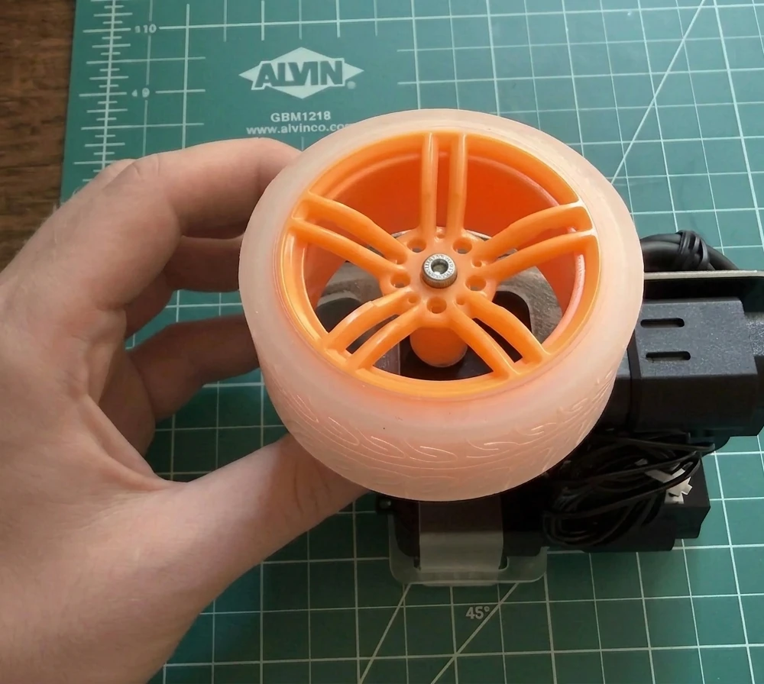
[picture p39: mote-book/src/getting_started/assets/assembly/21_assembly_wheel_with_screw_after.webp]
    
</div>

Repeat for the right wheel.

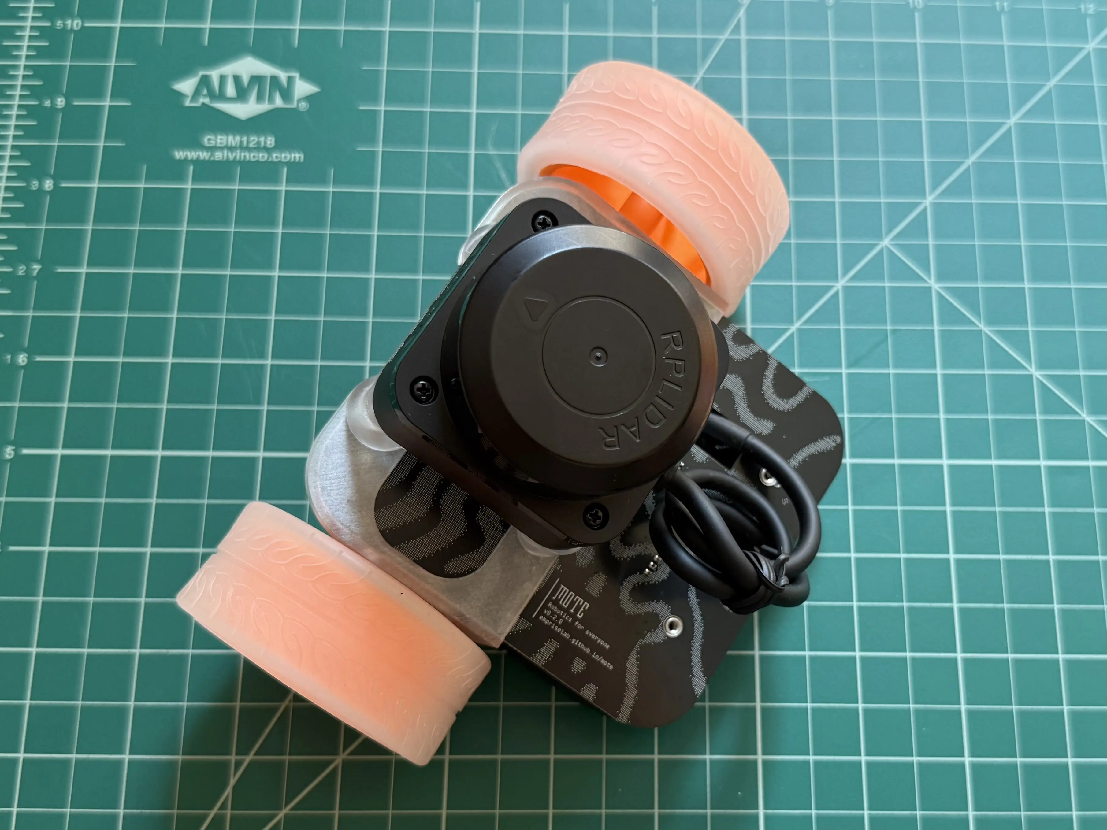
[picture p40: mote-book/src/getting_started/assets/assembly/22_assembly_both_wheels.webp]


## Tail Runner

Place a 6mm screw into the hole on the tail runner. Align the screw with the nut on the circuit board, then use the hex key to secure the tail runner to the circuit board. Repeat with the second 6mm screw and hole on the tail runner.

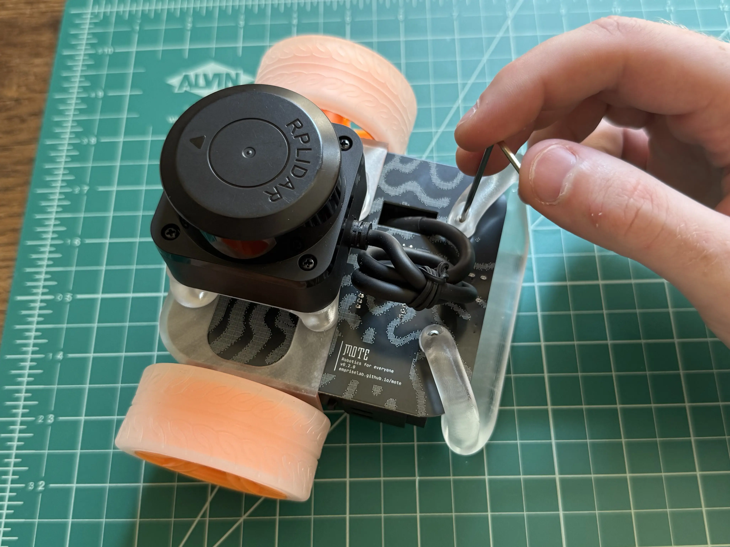
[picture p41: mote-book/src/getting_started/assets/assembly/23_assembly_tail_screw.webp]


## Success
You've successfully assembled your Mote!



## Next Steps

* [Update Firmware](./updating.md) - Update your Mote to the latest firmware version

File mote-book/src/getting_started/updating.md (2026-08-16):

# Updating Firmware

Before you can start using your Mote you'll need to program it with the latest firmware.

1. Download the latest version of mote-firmware: [MOTE_FW_TAG_PLACEHOLDER](MOTE_FW_URL_PLACEHOLDER).

2. While holding down the "BOOT" button on your Mote, connect the robot to your computer using the USB-C cable. Mote will appear as a USB drive titled "RP2350". 

3. Drag and drop the mote-firmware UF2 file into the USB drive. The drive will disappear a couple of seconds after dropping in the file.

## Next Steps

* [Configuration](./configuration.md) - configure Mote for use on your network

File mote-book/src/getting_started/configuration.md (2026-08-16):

# Configuration

This page will guide you through setting up your Mote for the first time.

## Connecting to WiFi

Mote communicates using WiFi. In order to work with Mote, we will log it onto a WiFi network.

1. Connect Mote to your computer using a USB-C cable.

2. Open [the Mote configuration page](../configuration). Click `[ connect ]` and select "Mote Serial".

3. Locate your WiFi network under "Networks". Click `[ connect ]` and enter your WiFi password. If you are using a public network, leave this field blank.

4. Press enter.

5. Wait 30 seconds for Mote to connect to the network. When the robot has successfully connected, you will see "currently connected" next to your WiFi in the detected networks list.

6. Under "Identification", take note your Mote's IP. You will need the IP later to establish communication with your robot.

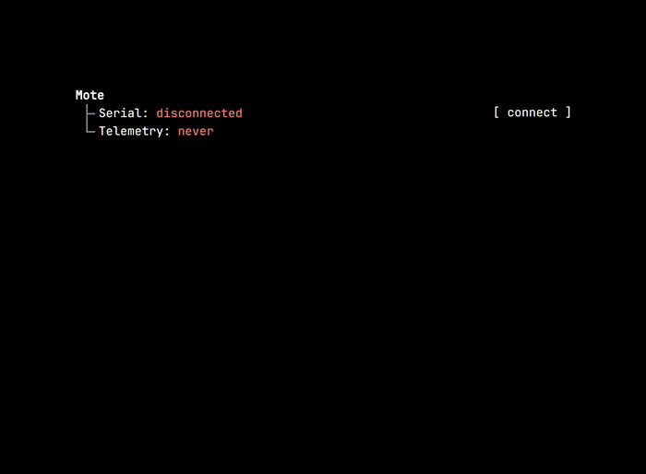
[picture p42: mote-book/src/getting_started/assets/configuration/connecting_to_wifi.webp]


## Give Your Mote a Name

You can use a friendly name to communicate with your Mote.

1. Connect Mote to your computer using a USB-C cable.

2. Open [the Mote configuration page](../configuration). Click `[ connect ]` and select "Mote Serial".

3. Next to "Unique Identifier", click `[ update ]`. 

4. Enter your Mote's name in the box. 

5. Press enter.



> [!IMPORTANT]
> Only one Mote can have a given name on a single network. If you expect other Motes to be used on the same network, choose a name that is unique enough to prevent conflicts.

## Next Steps

* [Hello World](./hello-world.md) - learn how to connect to your robot.

## Troubleshooting

### My network doesn't appear

Mote can only connect to 2.4 GHz networks. Make sure your router has the 2.4 GHz band enabled.

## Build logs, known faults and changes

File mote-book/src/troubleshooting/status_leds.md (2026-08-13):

# Status LEDs

The underside of Mote has three status LEDs indicating system faults.

## PWR LED

The power LED indicates if Mote is receiving sufficient voltage and current to operate.
Mote requires a USB C power bank that can deliver at least 1.5A.

🟥 - Not receiving sufficient power

The power supply cannot deliver 1.5A. 
LiDAR and motors are disabled.
Try a different power bank.

🟨 - Cannot read power supply current capacity

This is a firmware or hardware fault.
LiDAR and motors are disabled.

🟩 - Nominal

Mote has sufficient power.

## WiFi LED

The WiFi LED indicates if WiFi is initialized and connected to a network.

🟥 - WiFi has failed to initialize or is disabled

If the PWR LED is yellow or red, Mote does not have enough power to enable WiFi.
If the PWR LED is green, this is a hardware or firmware fault.

🟨 - WiFi has initialized but has not yet connected to a network

Reference [getting started - configuration](../getting_started/configuration.html#connecting-to-wifi) to connect your Mote to a network.

🟩 - Nominal

WiFi is configured and connected to a network.

## ERR LED

The error LED indicates if the system's sensors are powered on and communicating correctly.

🟥 - IMU fault

Power cycle the robot.

🟪 - LiDAR fault

Check that the LiDAR's cable is securely seated.
Power cycle the robot.

🟩 - Nominal

All sensors are operating as expected.

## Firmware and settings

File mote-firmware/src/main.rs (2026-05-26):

#![no_std]
#![no_main]
// generic_const_exprs is intentionally used in the LiDAR driver
#![allow(incomplete_features)]
// Embassy tasks pass ownership of hardware resources as arguments
#![allow(clippy::too_many_arguments)]
// Used minimally in the LiDAR driver, still very unstable
#![feature(generic_const_exprs)]
// Embassy-isms
#![feature(impl_trait_in_assoc_type)]
#![allow(async_fn_in_trait)]

extern crate alloc;

use defmt::info;
use embassy_executor::{Executor, Spawner};
use embassy_rp::clocks::{ClockConfig, CoreVoltage, clk_sys_freq};
use embassy_rp::config::Config;
use embassy_rp::multicore::{Stack, spawn_core1};
use embassy_time::Timer;
use embedded_alloc::LlffHeap as Heap;
use static_cell::StaticCell;
use {defmt_rtt as _, panic_probe as _};

use crate::tasks::*;

mod flash_config;
mod helpers;
mod tasks;

#[global_allocator]
static HEAP: Heap = Heap::empty();

const HEAP_SIZE: usize = 100 * 1024;

// Program metadata for `picotool info`.
#[unsafe(link_section = ".bi_entries")]
#[used]
pub static PICOTOOL_ENTRIES: [embassy_rp::binary_info::EntryAddr; 4] = [
    embassy_rp::binary_info::rp_program_name!(c"Mote"),
    embassy_rp::binary_info::rp_program_description!(c"A low cost, high confidence robot for education"),
    embassy_rp::binary_info::rp_cargo_version!(),
    embassy_rp::binary_info::rp_program_build_attribute!(),
];

static mut CORE1_STACK: Stack<10000> = Stack::new();
static EXECUTOR0: StaticCell<Executor> = StaticCell::new();
static EXECUTOR1: StaticCell<Executor> = StaticCell::new();

#[cortex_m_rt::entry]
fn main() -> ! {
    // Set up for clock frequency of 200 MHz, setting all necessary defaults.
    let mut config = Config::new(ClockConfig::system_freq(200_000_000).unwrap());
    config.clocks.core_voltage = CoreVoltage::V1_15;

    let p = embassy_rp::init(config);
    let r = split_resources!(p);

    info!("System clock frequency: {} MHz", clk_sys_freq() / 1_000_000);

    // Init the allocator
    unsafe {
        embedded_alloc::init!(HEAP, HEAP_SIZE);
    }

    spawn_core1(
        p.CORE1,
        unsafe { &mut *core::ptr::addr_of_mut!(CORE1_STACK) },
        move || {
            let executor1 = EXECUTOR1.init(Executor::new());
            executor1.run(|spawner| {
                spawner.spawn(
                    core1_task(
                        spawner,
                        r.usb_serial,
                        r.status_led,
                        r.lidar_uart,
                        r.imu,
                        r.encoder_driver,
                        r.left_encoder,
                        r.right_encoder,
                        r.drv8833_resources,
                        r.usb_power_detection,
                    )
                    .unwrap(),
                )
            });
        },
    );

    let executor0 = EXECUTOR0.init(Executor::new());

    executor0.run(|spawner| spawner.spawn(core0_task(spawner, r.wifi, r.flash).unwrap()));
}

#[embassy_executor::task]
async fn core0_task(spawner: Spawner, r: Cyw43Resources, flash_r: FlashResources) {
    info!("Core 0 spawned");

    spawner.spawn(flash_manager::flash_manager_task(flash_r).unwrap());
    info!("Flash INIT complete");

    Timer::after_millis(1000).await;
    wifi::init(spawner, r).await;
    info!("Wifi INIT complete");
}

#[embassy_executor::task]
async fn core1_task(
    spawner: Spawner,
    usb_r: UsbSerialResources,
    status_led_r: StatusLedResources,
    lidar_r: RplidarC1Resources,
    imu_r: ImuResources,
    encoder_driver_r: EncoderDriverResources,
    left_encoder_r: LeftEncoderResources,
    right_encoder_r: RightEncoderResources,
    motor_driver_r: DRV8833Resources,
    usb_power_r: UsbPowerDetectionResources,
) {
    info!("Core 1 spawned");

    /* Initial configuration state is set in core0_task after flash init */
    status_led::init(spawner, status_led_r).await;
    info!("Status LEDs INIT complete");

    usb_serial::init(spawner, usb_r).await;
    info!("USB Serial INIT complete");

    power_gate::init(spawner, usb_power_r).await;
    info!("Power Gate INIT complete");

    lidar::init(spawner, lidar_r).await;
    info!("LiDAR INIT complete");

    imu::init(spawner, imu_r).await;
    info!("IMU INIT complete");

    drive_base::init(
        spawner,
        motor_driver_r,
        encoder_driver_r,
        left_encoder_r,
        right_encoder_r,
    )
    .await;
    info!("Drive base INIT complete");
}

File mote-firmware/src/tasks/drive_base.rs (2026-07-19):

use defmt::{error, info};
use embassy_executor::Spawner;
use embassy_futures::select::select4;
use embassy_rp::pio::{Instance, Pio};
use embassy_rp::pwm::SetDutyCycle;
use embassy_rp::{gpio, pwm};
use embassy_time::{Duration, Instant, Ticker, Timer};
use mote_api::messages::mote_to_host::{Bit, BitResult, DriveBaseState, Message, WheelJointState};
use pid::Pid;

use crate::helpers::update_bit_result;
use crate::tasks::drive_base::encoder::PioEncoder;
use crate::tasks::drive_base::hbridge::PwmBridge;
use crate::tasks::wifi::{DATA_OFFLOAD_CHANNEL, MOTOR_COMMAND_CHANNEL};
use crate::tasks::{
    CONFIGURATION_STATE, DRV8833Resources, EncoderDriverResources, Irqs, LeftEncoderResources, RightEncoderResources,
    power_gate,
};

mod encoder;
mod hbridge;

/// Number of encoder pulses recorded per rotation.
/// This is specific to each model of TT motor, right now we use:
/// https://category.yahboom.net/products/encoder-tt-motor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
/// We may want to make this a configurable value to support different motors.
const ENCODER_PULSES_PER_ROTATION: u16 = 630;
/// Stiction prevents commands lower than this % from causing motion.
const MOTOR_DEADBAND_PERCENT: u8 = 52;
/// PDI commands lower than this % are filtered to prevent chattering due to
/// gearbox hysteresis.
const CONTROL_DEADBAND_PERCENT: f32 = 2.;
/// ms per iteration of the PID control loop.
const PID_CONTROL_LOOP_PERIOD_MS: u64 = 20;
/// ms per joint state telemetry value.
const TELEMETRY_LOOP_PERIOD_MS: u64 = 100;
/// Seconds of not receiving a command before deactivating the drive base.
const WATCH_DOG_TIMEOUT: u64 = 1;

/// Name of the encoder initialization built-in-test check.
const ENCODER_INIT_BIT: &str = "Init";
/// Names of the per-wheel encoder motion built-in-test checks.
const LEFT_ENCODER_BIT: &str = "Left Wheel";
const RIGHT_ENCODER_BIT: &str = "Right Wheel";

/// Update the result of one of the encoder built-in-test checks.
async fn set_encoder_bit(name: &'static str, result: BitResult) {
    let mut configuration_state = CONFIGURATION_STATE.lock().await;
    update_bit_result(&mut configuration_state.built_in_test.encoders, name, result);
}

/// Convert encoder pulses into radians
fn encoder_pulses_to_rad(pulses: i32) -> f32 {
    (pulses as f32 / ENCODER_PULSES_PER_ROTATION as f32) * 2. * core::f32::consts::PI
}

/// Represents a motor with an hbridge driver and quadrature encoder.
struct Motor<'d, T: SetDutyCycle, P: Instance, const SM: usize> {
    bridge: PwmBridge<T>,
    pio_encoder: PioEncoder<'d, P, SM>,
    pid: Pid<f32>,
    invert: bool,

    encoder_value: i32,
    pub joint_state: WheelJointState,
}

impl<'d, T: SetDutyCycle, P: Instance, const SM: usize> Motor<'d, T, P, SM> {
    fn new(bridge: PwmBridge<T>, encoder: PioEncoder<'d, P, SM>, invert: bool) -> Self {
        let ouput_limit = 100. - MOTOR_DEADBAND_PERCENT as f32;
        let pid = *Pid::<f32>::new(0., ouput_limit).p(8.0, ouput_limit).i(2.0, ouput_limit);

        Self {
            bridge,
            pio_encoder: encoder,
            pid,
            encoder_value: 0,
            invert,
            joint_state: WheelJointState {
                effort_percent: 0.0,
                velocity_rad_per_s: 0.0,
                position_rad: 0.0,
            },
        }
    }

    /// Set the target velocity in radians/second
    fn set_setpoint_rad_per_s(&mut self, setpoint: f32) {
        self.pid.setpoint(setpoint);
    }

    /// Step the motor's PID loop, targeting the latest setpoint commanded by
    /// set_setpoint
    async fn step(&mut self, dt_ms: u64) {
        let dt = dt_ms as f32 / 1000.;
        let inversion_coefficient = if self.invert { -1 } else { 1 };

        // Calculate rotation delta as pulses per second
        let last_encoder_read = self.encoder_value;
        self.encoder_value = inversion_coefficient * -self.pio_encoder.read().await;
        let measurement = encoder_pulses_to_rad(self.encoder_value - last_encoder_read);

        // Get the PID output accounting for the motor deadband
        let control_output = inversion_coefficient as f32 * self.pid.next_control_output(measurement / dt).output;
        let deadband_adjusted_output = if control_output > 0. {
            control_output + MOTOR_DEADBAND_PERCENT as f32
        } else {
            control_output - MOTOR_DEADBAND_PERCENT as f32
        };

        // If the command exceeds the control deadband, forward it to the hbridge with
        // the correct polarity
        if control_output > CONTROL_DEADBAND_PERCENT {
            self.bridge.forward(deadband_adjusted_output as u8).unwrap();
        } else if control_output < -CONTROL_DEADBAND_PERCENT {
            self.bridge.reverse(-deadband_adjusted_output as u8).unwrap();
        } else {
            self.bridge.stop().unwrap();
        }

        // Update the joint state
        self.joint_state.position_rad = encoder_pulses_to_rad(self.encoder_value);
        self.joint_state.velocity_rad_per_s = measurement / dt;
        self.joint_state.effort_percent = deadband_adjusted_output;
    }
}
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

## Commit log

2026-05-25 Fixes for motor rotation direction (#65)
    [drive_base.rs, tasks.rs]
2026-05-25 mote-hardware v0.2.0 (#63)
    Improvements to the pcb design for rev v0.2.0
    [imu.kicad_sch, mote-hardware.kicad_pcb, mote-hardware.kicad_sch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]
2026-05-26 Wifi power on init delay, try send instead of send for motor commands (#66)
    Fixes a power on wifi init failure + a bug that locked the wifi task
    when the drive base task was not emptying the command queue.
    [main.rs]
2026-05-26 Update mote-hardware version number on silk screen (#67)
    [mote-hardware.kicad_pcb]
2026-06-07 Small tweaks and fixes to the schematic (#68)
    [imu.kicad_sch, mote-hardware.kicad_pcb, mote-hardware.kicad_sch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]
2026-06-07 Update postition and rotation values for new components (#69)
    [motor.kicad_sch, power.kicad_sch, rp2354.kicad_sch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]
2026-06-28 Lower power requirements to 1.5A (#70)
    Testing shows that power draw with wifi, lidar, and motors active peaks
    at ~1.2A. We are safe to enable all peripherals if the power source
    signals it is 1.5A (7.5W) capable.
2026-07-07 C ffi use mote comms ffi + fix typo in mote-api (#56)
    [drive_base.rs, mote_to_host.rs]
2026-07-09 Configuration page overhaul (#73)
    Fixes a variety of functional and aesthetic issues with the
    configuration page and the associated state communication firmware.
    [drive_base.rs, mote_to_host.rs, power_gate.rs]
2026-07-12 More docs improvements (#75)
    * Improve color balancing of assembly images
    * Add gifs showing wifi connection and renaming mote
    * Improve rerun demo to use keyboard input for teleop
    * Fix bug with firmware link not getting updated
    * General clarity improvements of docs
2026-07-12 Drop vendored IMU library (#78)
    Remove vendored IMU library now that we're using the same version of the
    IMU that the library supports.
    Adjust some of the IMU calibration values to better suit a small robot.
2026-07-12 Switch to go-task instead of justfile (#79)
    Justfile makes me sad go-task makes me slightly happier
2026-07-19 Audit public APIs pre v1 release (#81)
    Align public APIs with language best practices
    * non_exhaustive labels where appropriate so new comms fields can be
    added without breaking the API
    * Required switching serialization from bitcode to postcard
    * Conform with https://rust-lang.github.io/api-guidelines/about.html
    * move from cbindgen based c FFI to cxx based C++ API
2026-07-19 Switch cxx linux aarch64 build to run on native rather than using qemu (#87)
2026-07-26 LiDAR driver sliding window (#88)
2026-08-05 Make imu NED frame consistent (#93)
    For some reason the IMU driver lib has the z-axis flipped. Invert this
    manually in our driver shim.
    [imu.rs]
2026-08-13 Pin mdbook version (#97)
